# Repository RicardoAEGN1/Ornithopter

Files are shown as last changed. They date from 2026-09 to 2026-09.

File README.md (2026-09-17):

# 🚁 ORNITHOPTER

> Drone quadcóptero estilo **Dune** (thopter), controlado por **ESP32** com firmware open-source **ESP-Drone** (Espressif). Projeto escolar de eletrónica — construído componente a componente, sem kits.

**📖 Site do projeto (GitHub Pages):** https://ricardoaegn1.github.io/Ornithopter/ — apresentação, BOM interativo e todos os docs.

## Esquema de ligações (visão geral)

Esquema de ligações Ornithopter

*Raspberry Pi (estação de solo, sem soldas) → Wi-Fi → ESP32 no drone → 4 motores com MOSFETs + IMU. Ordem de soldadura e legenda no diagrama; detalhes em [`docs/wiring.md`](docs/wiring.md) e [`docs/ground-station.md`](docs/ground-station.md).*

## Números-chave

| Métrica | Valor |
|---|---|
| Peso total (AF) | ~78 g |
| Empuxo | ~150 g (razão 2,0×) |
| Autonomia | 6–11 min |
| Custo total | **44,30 €** (orçamento 70 €) |
| Loop de controlo | PID 500 Hz |
| Controlo | App iOS/Android via Wi-Fi 2,4 GHz |

## Estrutura

```
docs/               Viabilidade, BOM (CSV p/ Excel), pinout, plano de construção
cad/                Modelo paramétrico OpenSCAD (frame + carenagem estilo Dune)
presentation/       Apresentação HTML do projeto (abrir no browser)
ground-station/     Estação de solo em Raspberry Pi (visão + controlo autónomo)
assets/             Esquema à mão do criador + diagrama de ligações SVG
tools/              build_site.py — gera o site do GitHub Pages
site/               (gerado) site estático publicado no Pages
```

> O site (`site/`) é gerado automaticamente por `.github/workflows/pages.yml` a cada push para `main`.

## Arquitetura (v2 — autonomia)

```
Telemóvel/PC ──► Raspberry Pi (câmara + OpenCV) ──UDP/CRTP──► ESP32 ──► 4 motores
      painel         seguimento ArUco · altitude ·       PID interno · mixer
                     rotação · velocidades/direção       (firmware esp-drone)
```

O drone leva um marcador ArUco; a RPi calcula posição/altitude/rotação por visão e envia
setpoints — ver [`docs/ground-station.md`](docs/ground-station.md).

## Documentos

- [`docs/viability.md`](docs/viability.md) — estudo de viabilidade (arquitetura, empuxo/peso, potência, estabilidade)
- [`docs/bom.md`](docs/bom.md) — lista de materiais com fornecedores e custos
- [`docs/bom.csv`](docs/bom.csv) — mesma lista em CSV (abre no Excel com colunas certas)
- [`docs/ground-station.md`](docs/ground-station.md) — estação de solo RPi: visão, controlo, segurança
- [`docs/algorithms.md`](docs/algorithms.md) — sistemas e algoritmos: camadas de controlo, PID cascata, mixer, coordenação e multi-drone
- [`ground-station/main.py`](ground-station/main.py) — skeleton executável (FastAPI + OpenCV)
- [`docs/wiring.md`](docs/wiring.md) — pinout ESP32 e esquema de ligações
- [`docs/build-plan.md`](docs/build-plan.md) — plano de construção em blocos com critérios de passe
- [`cad/ornithopter.scad`](cad/ornithopter.scad) — CAD paramétrico (OpenSCAD → STL)
- [`presentation/ornithopter.html`](presentation/ornithopter.html) — apresentação do projeto

## Stack

| Camada | Tecnologia |
|---|---|
| Flight controller | ESP32-WROOM-32 (escola) |
| Firmware | [espressif/esp-drone](https://github.com/espressif/esp-drone) (ESP-IDF v5.0, GPL-3.0) |
| IMU | MPU-9250 (I2C) |
| Motores | 4× coreless 8520 + MOSFET AO3400A |
| Bateria | LiPo 1S 450 mAh 25C |
| App | [ESP-Drone-Android](https://github.com/EspressifApps/esp-drone-android) / iOS |
| Estação de solo | Raspberry Pi 4 + OpenCV (ArUco) · FastAPI |
| CAD | OpenSCAD |

*"The spice must flow."* 🕌

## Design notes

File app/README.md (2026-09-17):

# 📱 Ornithopter App (Expo)

App de controlo do drone Ornithopter em **Expo/React Native** — corre em Android/iOS via Expo Go, sem compilar nada.

## Arquitetura de comando

```
TELEMÓVEL (app Expo)      RASPBERRY PI (FastAPI)         ESP32 (esp-drone)
┌──────────────────┐     ┌──────────────────────┐      ┌───────────────┐
│ botões + telem.  │────►│ POST /takeoff /land  │────► │ mixer → 4     │
│ telemetria live  │◄────│ WS   /ws/telemetry   │◄──── │ motores + IMU │
└──────────────────┘HTTP └──────────────────────┘ UDP  └───────────────┘
```

- A app **nunca** fala com o drone diretamente — só com a estação de solo (RPi). É ela que aplica as regras de segurança (watchdog, geofence, bateria) a *qualquer* comando, venha ele da app, do painel web ou de um script.
- Telemetria em tempo real por WebSocket (`/ws/telemetry`): modo, posição x/y/z, atitude, bateria, estado do marcador.

## Ecrãs

1. **Ligação** — IP da estação de solo (rede da escola)
2. **Painel** — telemetria live + DECOLAR / ATERRAR
3. **EMERGENCY** — botão sempre visível, motores OFF imediato
4. *(próximo)* **Joystick virtual** — 2 pans → `/goto x,y`

## Correr

```bash
cd app
npm install
npx expo start        # abre no telemóvel com Expo Go (mesma rede Wi-Fi da RPi)
```

## Integração com a estação de solo

A app consome exatamente os endpoints já definidos em [`docs/ground-station.md`](../docs/ground-station.md):

| App | Endpoint RPi |
|---|---|
| LIGAR | `GET /` (painel) + `WS /ws/telemetry` |
| DECOLAR | `POST /takeoff` |
| ATERRAR | `POST /land` |
| Ir para (x,y) | `POST /goto?x=&y=` |
| EMERGENCY | `POST /emergency` |

## Estado

- [x] Esqueleto Expo (ligação, telemetria, comandos de voo)
- [ ] Joystick virtual (gestos → /goto)
- [ ] Modo FPV (stream MJPEG da câmara da RPi) — **extra**
- [ ] Config persistente do IP (AsyncStorage)

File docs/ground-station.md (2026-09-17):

# Estação de Solo — Raspberry Pi (backend de controlo)

> A Raspberry Pi da escola recebe comandos da **app Expo (telemóvel)** e do painel web, aplica as regras de segurança e envia setpoints ao ESP32. A **câmara** é um **extra opcional** de demonstração (seguimento autónomo por ArUco) — o drone voa e é comandável mesmo sem ela.

## 1. Modos de operação

| Modo | Câmara | Seguimento | Quem comanda |
|---|---|---|---|
| **A — Manual (base)** | ❌ | ❌ | App Expo / painel web → RPi → drone |
| **B — Autónomo (extra)** | ✔ | ✔ ArUco | Mission planner da RPi (demo de capacidade) |

No modo A, a altitude e a estabilização ficam a cargo do firmware (height-hold com barómetro BMP280 opcional) e dos comandos diretos da app. O modo B demonstra coordenação por visão — é o *show-off* científico, não o requisito.

## 2. Arquitetura

```
        ┌───────────────────────────── Wi-Fi 2,4 GHz ─────────────────────────────┐
        │                 UDP · protocolo CRTP (Crazyflie)                        │
        ▼                                                                         │
┌──────────────────┐        ┌──────────────────────────────────────────────────┐  │
│  ORNITHOPTER     │        │  RASPBERRY PI 4 (estação de solo)                │  │
│  ESP32 + MPU9250 │◄───────│  · câmara aponta para a zona de voo              │  │
│  firmware        │  setp. │  · OpenCV: deteta o marcador no drone            │  │
│  esp-drone       │        │  · calcula x, y, z (altitude), roll, pitch, yaw  │  │
└──────────────────┘        │  · PID externo → velocidades por motor           │  │
        ▲                   │  · FastAPI: painel de controlo no browser        │  │
        │                   └──────────────────────────────────────────────────┘  │
        └────────────────── telemetria (estado) ─────────────────────────────────┘
```

**Porquê esta divisão?**
- O ESP32 mantém o **PID interno** (estabilização a 500 Hz com o IMU) — exige timing rígido, não deve partilhar com visão.
- A RPi faz o **loop externo** (posição/altitude a ~30 Hz) — é o padrão Crazyflie: *position controller* no chão, *stabilizer* no drone.
- Protocolo: **CRTP over UDP**, o mesmo que o cfclient usa — não inventamos nada.

## 3. Como é que o drone é seguido (extra opcional)

O drone leva um **marcador ArUco impresso** (4×4 cm) na parte de baixo/inferior da carenagem:

1. A câmara da RPi captura a ~30–60 fps.
2. OpenCV (dicionário `aruco.DICT_4X4_50`) devolve os 4 cantos do marcador.
3. De cada frame extraímos:
   - **x, y** (posição no plano) → centróide dos cantos, convertido para cm com calibração da câmara.
   - **z (altitude)** → `solvePnP` com o tamanho real do marcador (4 cm conhecidos) — sem sensor extra!
   - **yaw (rotação)** → ângulo do vetor entre cantos do marcador.
   - **roll/pitch estimados** → mudança da forma aparente do quadrilátero (aproximação; o roll/pitch fino continua a vir da telemetria do IMU).
4. Um PID externo compara com o alvo (ex.: pairar a 50 cm sobre um ponto) e gera **setpoints de roll/pitch/thrust/yaw-rate**.
5. Os setpoints vão por UDP ao ESP32, que os mistura nos 4 motores.

**Alternativa ainda mais simples (Plano B):** 2 marcadores de cores (uma em cada braço frontal) → OpenCV `inRange` por cor → mais robusto a distância e luz, sem dependência do módulo `cv2.aruco`.

## 3. Controlo por app Expo (telemóvel)

O telemóvel fala **sempre com a RPi** (nunca com o drone):

```
app Expo ──HTTP POST /takeoff /land /goto /emergency──► RPi ──UDP──► ESP32
app Expo ◄──WebSocket /ws/telemetry (10 Hz)──────────── RPi ◄─────── ESP32
```

- **Porquê passar sempre pela RPi?** Ponto único de segurança: a RPi valida geofence, bateria e watchdog **antes** de retransmitir qualquer comando — venha ele da app, do painel web ou do planner autónomo.
- A app (pasta `app/`) tem: ecrã de ligação por IP, telemetria live, DECOLAR/ATERRAR e botão EMERGENCY sempre visível.
- *Extra:* stream MJPEG da câmara no ecrã da app (FPV pela RPi) — só útil no modo B.

## 4. Mapa das funções que propuseste → implementação

| Função (a tua ideia) | Onde corre | Como |
|---|---|---|
| **Calcular altitude** | RPi (visão) | `solvePnP` com marcador ArUco de 4 cm conhecidos |
| **Fazer o seguimento dos corpos em tempo real** | RPi (visão) | OpenCV ArUco / cores; IDs diferentes = "corpos" diferentes (multi-drone no futuro) |
| **Gerir o movimento do drone** | RPi (controle) | Máquina de estados: IDLE→TAKEOFF→HOVER→GOTO→LAND + PID externo |
| **Calcular a rotação atual do drone** | RPi (visão) + ESP32 (IMU) | Yaw do marcador por visão; roll/pitch finos por telemetria CRTP do IMU |
| **Calcular a velocidade a usar em cada motor e a direção** | ESP32 (mixer) | Setpoints → PID interno → mistura X: `M1=T−P−R+Y, M2=T+P−R−Y, M3=T+P+R+Y, M4=T−P+R−Y` |

## 6. Endpoints do painel e da app (FastAPI)

| Método | Rota | Ação |
|---|---|---|
| GET | `/` | Painel com vídeo + telemetria ao vivo |
| POST | `/takeoff` | Decolagem para altitude alvo (default 50 cm) |
| POST | `/land` | Aterrar |
| POST | `/goto {x,y,z}` | Ir para ponto |
| POST | `/emergency` | Motores OFF imediatamente |
| WS | `/ws/telemetry` | Telemetria em tempo real (x, y, z, r/p/y, bateria) |

## 7. Segurança

- Botão físico de **kill** na RPi (GPIO) e comando `/emergency` sempre ativo.
- **Watchdog:** se a RPi perder o marcador > 1 s → `LAND` automático.
- Geofence por software (zona de voo máx. 2×2 m, altura máx. 1,5 m).
- Bateria do drone < 3,4 V → aterragem automática.
- Sempre: voo amarrado nas primeiras sessões.

## 8. Requisitos (tudo grátis, tudo na escola)

```
Raspberry Pi 4 (escola) + câmara CSI/USB (escola)
Python 3.9+ · opencv-python · opencv-contrib-python (aruco) · fastapi · uvicorn · numpy
ESP32 já a correr esp-drone (modo CRTP over UDP já suportado)
```

---

*Referência: arquitetura cfclient/Crazyflie (position controller externo + stabilizer interno) e `espressif/esp-drone`.*

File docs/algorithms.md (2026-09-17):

# Sistemas e Algoritmos — Coordenação, Navegação e Controlo

> Documento teórico do Ornithopter: como as partes se coordenam (RPi ↔ ESP32 ↔ motores) e que algoritmos fazem o drone pairar, navegar e aterrar. Sem código — só conceitos, diagramas e matemática.

## 1. Visão global: três camadas de controlo

```
┌──────────────────────────────────────────────────────────────┐
│  CAMADA 3 — MISSION PLANNER (RPi, ~1 Hz)                     │
│  máquina de estados: IDLE → TAKEOFF → HOVER → GOTO → LAND    │
│  decide O QUÊ fazer (pontos de passagem, geofence, segurança)│
├──────────────────────────────────────────────────────────────┤
│  CAMADA 2 — POSITION CONTROLLER (RPi, ~30 Hz)                │
│  PID externo: posição (x,y,z) → setpoints de atitude         │
│  decide COMO se mover (roll/pitch/thrust desejados)          │
├──────────────────────────────────────────────────────────────┤
│  CAMADA 1 — STABILIZER (ESP32, 500 Hz)                       │
│  PID interno: atitude desejada → velocidades dos 4 motores   │
│  (mixer X) usando o giroscópio/accelerómetro do MPU-9250     │
└──────────────────────────────────────────────────────────────┘
```

Esta divisão é o padrão da indústria (Crazyflie, PX4, ArduPilot): **quanto mais rápido o loop, mais perto do hardware**. O ESP32 não sabe "para onde ir" — só sabe manter a atitude que lhe mandam; a RPi não toca nos motores — só manda intenções.

## 2. Estimador de atitude (ESP32): filtro complementar

O giroscópio é rápido mas deriva; o acelerómetro é estável mas ruidoso. O **filtro complementar** junta os dois:

```
ângulo = α · (ângulo + gyro · dt) + (1 − α) · atan2(acc_y, acc_z)

α ≈ 0,98  →  confia 98 % no gyro entre medições,
             corrige 2 % com o acelerómetro (que conhece "para baixo")
```

- Frequência de corte: `α = τ/(τ+dt)`, com τ ≈ 0,5 s.
- O yaw não pode ser corrigido pelo acelerómetro (a gravidade não gira no plano horizontal) → usa-se o **magnetómetro** do MPU-9250, ou aceita-se deriva lenta de yaw (ok para demo indoor).

## 3. PID em cascata (ESP32): o coração da estabilização

Dois PIDs encadeados por eixo (roll, pitch, yaw-rate):

```
setpoint atitude (graus)          ← vem da RPi
        │
        ▼
  ┌─────────┐  erro de ângulo   ┌─────────┐  velocidade
  │ PID     │ ────────────────►  │ PID     │ ───────────►  mistura
  │ ANGULAR │   (graus)          │ RATE    │               X (M1..M4)
  └─────────┘                    └─────────┘                    │
        ▲                             ▲                        ▼
   ângulo estimado               gyro (rad/s)          PWM 20 kHz nos MOSFETs
   (filtro compl.)               a 1 kHz
```

**Porquê cascata?** O loop interno (rate) é 10× mais rápido e amortece perturbações (rajadas, vibração) antes de chegarem ao ângulo — o mesmo princípio de um piloto automático real.

**Sintonia (Ziegler–Nichols na bancada):**
1. Ki = Kd = 0; subir Kp até oscilar → Kp_final = 0,6·Kp_osc
2. Kd ≈ 0,1·Kp (amortecer); Ki pequeno (corrigir deriva de hover)
3. Valores de partida típicos para mini-quads: rate Kp≈0,25 · angular Kp≈4,5

## 4. Mistura X (mixer): setpoints → 4 motores

```
M1 (CCW) = T − P − R + Y      M2 (CW)  = T + P − R − Y
M4 (CW)  = T − P + R − Y      M3 (CCW) = T + P + R + Y

T = thrust  P = pitch  R = roll  Y = yaw-rate
```

| Movimento | O que muda |
|---|---|
| Subir | T igual nos 4 |
| Pitch (frente/trás) | diferença frente ↔ trás |
| Roll (esq/dir) | diferença esquerda ↔ direita |
| Yaw (rodar) | pares CW vs CCW (torque reação) |

Cada Mi é normalizado a [0..1] antes do PWM. Se algum ultrapassa 1 (saturação), reduz-se T igualmente nos 4 — mantém a atitude em vez do empuxo (regra de segurança).

## 5. Algoritmos de coordenação RPi ↔ drone

### 5.1 Seguimento visual (ArUco)

1. Detetar cantos do marcador (dicionário 4×4) a 30 fps.
2. `solvePnP`: com 4 cantos + tamanho real (40 mm) → rotação e translação da câmara → **x, y, z do drone**.
3. Suavizar com **filtro de Kalman 1D** por eixo (prevê entre frames; rejeita outliers de deteção falhada).
4. Se perdido > 1 s → trigger de segurança (LAND).

### 5.2 Controlo de posição (PID externo na RPi)

```
erro_x = x_alvo − x_drone  →  pitch_cmd = Kp·erro_x + Ki·∫erro + Kd·(derivada)
erro_z = z_alvo − z_drone  →  thrust_cmd = hover_thrust + PID_z(erro_z)
```

- **Estratégia antiderivada (derivative kick):** derivar a medição, não o erro — evita saltos quando o alvo muda.
- **Integral limitado (anti-windup):** clampa ∫ para não acumular enquanto o drone arranca.

### 5.3 Máquina de estados (mission planner)

```
        takeoff()            z ≥ 95% alvo          goto(x,y)
IDLE ───────────► TAKEOFF ────────────────► HOVER ◄────► GOTO
  ▲                  │                        │             │
  │ land()/auto      │ perdeu marcador        │             │ chegou (<40mm)
  ▼                  ▼                        ▼             ▼
LAND ◄──────── bateria<3.4V ◄── watchdog ── (qualquer estado)
  │
  ▼ z≈0 → motores OFF → IDLE
```

Transições de emergência (watchdog, geofence, bateria) têm **prioridade absoluta** sobre comandos do utilizador.

### 5.4 Coordenação multi-"corpos" (extensão futura)

O dicionário ArUco 4×4 tem 50 IDs → cada drone pode ter um ID. A RPi faz **seguimento simultâneo** e um **alocador de alvos** evita colisões:
- **Caixas de exclusão:** cada drone tem um cilindro de 50 cm; o planner rejeita alvos dentro do cilindro de outro.
- **Prioridade fixa por ID** (determinístico, fácil de explicar na defesa).
- **Alternativa elegante:** algoritmo *repulsion* — cada drone recebe um empurrão virtual proporcional à proximidade do outro (campo potencial artificial).

## 6. Segurança por camadas (defesa em profundidade)

| Camada | Mecanismo | Atuação |
|---|---|---|
| 1 — Hardware | pull-down nos gates | motores OFF se ESP32 reinicia |
| 2 — Firmware | failsafe RC/Wi-Fi | perdeu ligação → motores OFF |
| 3 — Software RPi | watchdog do marcador | LAND automático |
| 4 — Mission | geofence + bateria | rejeita alvos fora; LAND < 3,4 V |
| 5 — Humano | botão EMERGENCY / kill | motores OFF imediato |

## 7. O que medir na bancada (para provar na defesa)

- Latência RPi→ESP32 (setpoint): alvo < 50 ms (Wi-Fi local)
- Latência de loop de visão: alvo < 33 ms/frame (30 fps)
- Erro estático de hover: alvo < ±10 cm (x,y) e < ±5 cm (z)
- Overshoot no degrau de setpoint: alvo < 20 % da altura degrau

---

*Referências: filtro complementar (Kalman/colibry), PID cascata do Crazyflie (`bitcraze/crazyflie-firmware`), ArUco (S. Garrido-Jurado, 2014), mistura X do esp-drone.*

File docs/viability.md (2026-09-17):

# Ornithopter — Estudo de Viabilidade

> Drone estilo **Dune** (thopter), controlado por **ESP32** com firmware open-source **ESP-Drone** (Espressif). Mini brushed, voo estabilizado por app de telemóvel via Wi-Fi. Orçamento máximo: **70 €**.

---

## 1. Decisão de arquitetura

**Porquê um quadcóptero com carenagem estilo Dune (e não um ornitóptero de asas batentes)?**

| Critério | Ornitóptero real (asas batem) | Quadcóptero "thopter" |
|---|---|---|
| Controlo de voo | Muito difícil (ninguém faz estabilização académica disto) | Maduro: firmware Crazyflie/ESP-Drone pronto |
| Risco de não voar | Alto | Baixo |
| Estética Dune | Exata | Adaptada (asas fixas escondem os 4 rotores) |
| Foco do trabalho | Mecânica (ruido, falha) | Eletrónica + software (o que a aula avalia) |

**Veredicto:** quadcóptero X-frame com uma carenagem superior em forma de "thopter" e 4 anéis de proteção estilo motor-gondola de Dune. Voa de verdade e tem a estética.

## 2. Configuração de voo

- **Frame:** X quadrado, 65–80 mm (motor-to-motor), chassi em PLA/PETG impresso 3D ou contraplacado 2 mm.
- **Motores:** 4 × **8520 coreless brushed** (8,5 mm × 20 mm), 3,7 V, ~55 000 rpm, ~15–20 g de empuxo cada a 3,7 V.
- **Hélices:** 65 mm (2 pares CW + CCW), tipo *Gemfan 65mm* — o par CW/CCW é o que permite ao firmware contrariar o *torque* (yaw).
- **Bateria:** **1S LiPo 300–450 mAh** (3,7 V nominal, 4,2 V carregada), com conector JST-PH 2.0.
- **Controlador:** **ESP32-WROOM-32** (fornecido pela escola) — faz de *flight controller* + *radio link* Wi-Fi (2,4 GHz), sem rádio extra.
- **IMU:** **MPU-9250** (giroscópio + acelerómetro + magnetómetro, I2C/SPI) — recomendado pelo schematic do ESP-Drone; alternativas: MPU-6050 (só giro+acc) ou ICM-42688.
- **Driver dos motores:** 4 × MOSFET N-channel em SOT-23 (ex.: **AO3400A**) com resistor de gate 100 Ω e flyback diode, um por motor — é a arquitetura do schematic oficial do ESP-Drone.

## 3. Contas de voo (a parte que interessa provar)

**Peso estimado (AF — all-up weight):**

| Componente | Peso |
|---|---|
| 4 × motor 8520 | ~4 × 5,0 g = 20 g |
| 4 × hélice 65 mm | ~4 × 0,5 g = 2 g |
| Bateria 1S 450 mAh | ~13 g |
| ESP32-WROOM-32 (devkit) | ~10 g |
| MPU-9250 breakout | ~2 g |
| Chassi + carenagem PLA | ~20–25 g |
| Cablagem, MOSFETs, parafusos, LEDs | ~8 g |
| **Total** | **~75–80 g** |

**Empuxo:** 4 motores × ~17 g = **~68 g** a 3,7 V... insuficiente para um AF de 80 g.
- A 4,0–4,2 V (bateria cheia) o empuxo sobe para ~22 g/motor → **~88 g**.
- **Regra de ouro:** empuxo ≥ 2× peso. Para AF = 80 g queremos **~160 g de empuxo**.
- **Solução:** usar a variante **820 coreless (55 000 rpm, ~25 g empuxo)** ou motores 8520 "high thrust" (~24 g), ou reduzir o AF para <45 g com chassi minimalista (estilo Crazyflie: ~27 g).

**Alvo final:** AF ≈ 70 g, empuxo ≈ 140–160 g → razão empuxo/peso **2,0–2,3** ✔ (hover a ~45–50 % de throttle, sobra para manobrar).

**Corrente:** 4 motores × ~0,6 A em hover ≈ **2,4 A**; pico ~5 A. Uma 1S 450 mAh a 25C entrega 11 A — folga ✔.
**Autonomia:** 450 mAh / 2,4 A ≈ **11 min em hover** (realista: 6–8 min com manobras).
**Potência:** 3,7 V × 2,4 A ≈ **9 W em hover**, ~18 W pico.

## 4. Estabilidade (o que o firmware faz)

- **Loop de controlo a 500 Hz:** PID em cascata (rate → attitude), igual ao Crazyflie. O MPU-9250 mede rotações a 1 kHz.
- **Modos:** *Stabilize* (ângulos limitados, sempre estável), *Height-hold* (com barómetro BMP280 opcional, +2 €) e *Position-hold* (com fluxo ótico PMW3901, +12 € — opcional, fica fora do orçamento base).
- **Mistura X:** firmware mistura throttle + roll + pitch + yaw nos 4 motores (M1..M4), CW/CCW alternados.

## 5. Ligações (esquema elétrico resumido)

```
Bateria 1S ──┬── VCC 3,7V ──┬─────────────┬──────────────┐
             │              │             │              │
           (SW)          MOSFET M1..M4 (AO3400A)    VIN ESP32
             │              │             │              │
             └── GND ───────┴── GND ──────┴──────────────┘
                            ▲
              Gate de cada MOSFET ◄── GPIO 4/12/13/14 (ESP32) via 100Ω
              MPU-9250: SDA→GPIO21, SCL→GPIO22 (I2C, 3V3 + GND)
```

- Motores: + do motor ao + da bateria; − do motor ao **drain** do MOSFET; **source** ao GND.
- ESP32 alimenta-se pela bateria via pino **VIN/5V** (regulador onboard aguenta 4,2 V — confirmar devkit).
- LEDs indicadores em GPIO 2 (e ring WS2812 opcional para efeito "spice" laranja de Dune).

## 6. Software (o que já existe, não inventamos)

- **Firmware:** `espressif/esp-drone` (GitHub) — GPL3.0, portado do Crazyflie. Suporta ESP32/ESP32-S2/S3, IDF v5.0.
- **App:** `ESP-Drone-iOS` / `ESP-Drone-Android` (open-source) — liga por Wi-Fi ao drone e controla.
- **O que fazemos:** configurar GPIOs no `menuconfig` para os nossos pinos, calibrar IMU, ajustar PID.

## 7. Riscos e mitigação

| Risco | Mitigação |
|---|---|
| Empuxo insuficiente | Motores "high thrust" ou chassi < 50 g; testar empuxo antes de montar |
| Peso da carenagem | Carenagem em PLA fino (0,8 mm) ou cartão plástico; ≤ 25 g |
| IMU barata descalibrada | Calibração do firmware + montagem firme com espuma dupla-face |
| Interferência Wi-Fi no IMU | Afastar MPU-9250 do ESP32 ≥ 2 cm; fios torcidos |
| Soldadura de MOSFET SOT-23 | Usar adaptador SOT-23→DIP ou MOSFET TO-92 (mais fácil de soldar) |

---

*Fonte: repositório `espressif/esp-drone` (GitHub), especificações típicas de motores coreless 8520/820 de fabricantes (estimativas), cálculos próprios.*

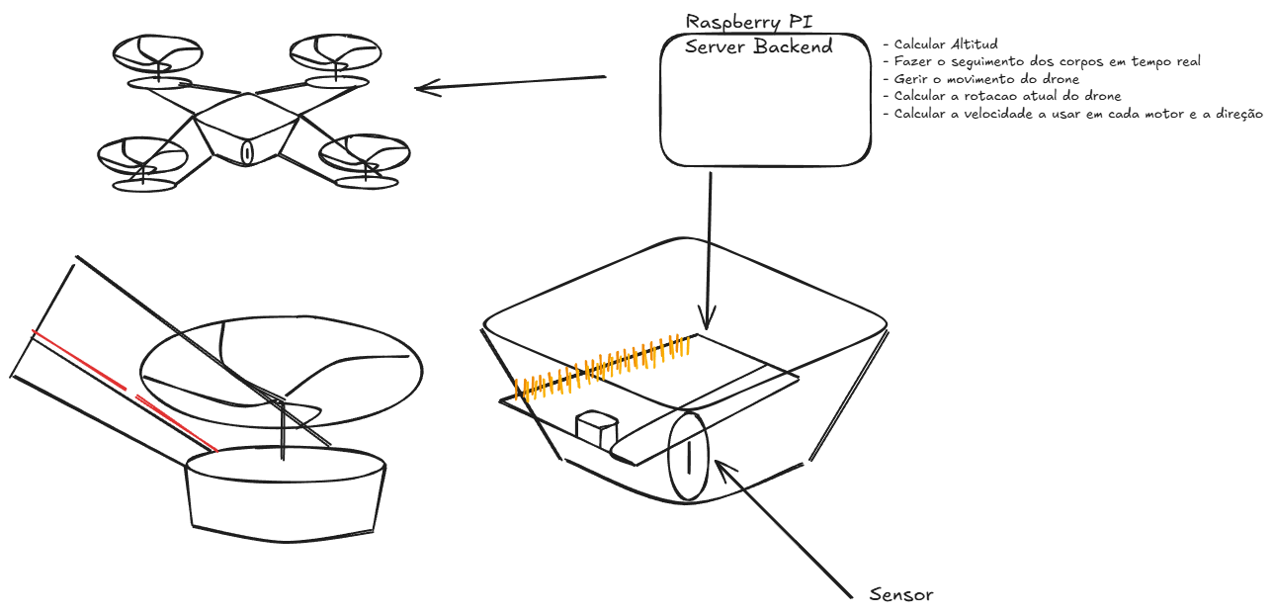
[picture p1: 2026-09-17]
assets/schema-raspberry-v1.png

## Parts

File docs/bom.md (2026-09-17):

# Ornithopter — Lista de Materiais (BOM)

> Orçamento máximo: **70 €**. A escola fornece: **ESP32 devkit, ferro de soldar + estanho, cabos, multímetro** (valor evitado: ~15 €).

## 1. Componentes comprados

| # | Componente | Especificação | Fornecedor | Qtd | Preço un. | Subtotal |
|---|---|---|---|---|---|---|
| 1 | Motores coreless 8520 "high thrust" | 8,5×20 mm, 3,7 V, ~24 g empuxo (2× CW + 2× CCW) | AliExpress / Amazon.es | 4 | 2,50 € | **10,00 €** |
| 2 | Hélices 65 mm (2 CW + 2 CCW) | Gemfan 65 mm ou equivalentes | AliExpress / Amazon.es | 4 (+4 reserva) | 0,40 € | **3,20 €** |
| 3 | Bateria LiPo 1S 450 mAh 25C | Com JST-PH 2.0 e protetor | AliExpress / loja RC local | 1 | 7,50 € | **7,50 €** |
| 4 | Carregador 1S USB (micro/USB-C) | Balanceador simples 1S | AliExpress / loja RC local | 1 | 6,00 € | **6,00 €** |
| 5 | IMU MPU-9250 (GY-9250 breakout) | Giro + acel + mag, I2C/SPI | AliExpress / Amazon.es | 1 | 4,50 € | **4,50 €** |
| 6 | MOSFET AO3400A (ou TO-92 equivalente) | N-channel, gate 2,5–4 V | AliExpress (lote 50 pcs) | 4 | 0,10 € | **0,40 €** |
| 7 | Resistores (100 Ω gate, 10 kΩ pull-down) | Kit básico 1/4 W | Escola ou AliExpress | 8 | 0,05 € | **0,40 €** |
| 8 | Flyback diodes 1N4148 | Proteção dos MOSFETs | Escola / AliExpress | 4 | 0,05 € | **0,20 €** |
| 9 | Conector JST-PH 2.0 (par) | Fio para bateria→placa | AliExpress | 1 | 1,00 € | **1,00 €** |
| 10 | Fio silicone 22 AWG (verm/preto) | 1 m de cada | Escola / AliExpress | 1 | 2,00 € | **2,00 €** |
| 11 | Proto-board perfurada ou placa DIY | Base para montar os MOSFETs | Loja eletrónica local | 1 | 3,00 € | **3,00 €** |
| 12 | Filamento PLA (chassi + carenagem) | ~40 g; impressão na escola ou 3DHub | Escola (grátis) ou serviço | 1 | 4,00 € | **4,00 €** |
| 13 | LEDs + resistores (indicador laranja "spice") | 5 mm + 220 Ω | Escola / AliExpress | 2 | 0,10 € | **0,20 €** |
| 14 | Velcro dupla-face + abraçadeiras | Fixação bateria e IMU | Loja local | 1 | 1,50 € | **1,50 €** |
| 15 | Parafusos M2 + porcas | Montagem motores | Loja local / escola | 8 | 0,05 € | **0,40 €** |

**Total comprado: ≈ 44,30 €** ✔ dentro dos 70 € (folga de ~25 € para portes, reservas e imprevistos).

## 2. Componentes fornecidos pela escola (custo 0 €)

| Componente | Valor evitado |
|---|---|
| ESP32 devkit (WROOM-32) | ~8,00 € |
| Ferro de soldar + estanho + fluxo | ~20,00 € |
| Cabos jumpers / fio | ~2,00 € |
| Multímetro (testes) | ~10,00 € |
| **Total evitado** | **~40,00 €** |

## 3. Opcionais (se sobrar orçamento)

| Componente | Preço | Efeito |
|---|---|---|
| Barómetro BMP280 | ~2 € | Modo *height-hold* do firmware |
| Fluxo ótico PMW3901 | ~12 € | Modo *position-hold* (hover sem deriva) |
| Anel LED WS2812 | ~2 € | Efeito visual "spice" laranja |

## 4. Notas de compra

- **AliExpress:** mais barato mas 2–4 semanas de espera → encomendar **já**.
- **Amazon.es:** entrega 24–72 h, ~30 % mais caro — usar para bateria e carregador (críticos).
- **Lojas PT:** Robotshop.pt, Bricogeek (ES), lojas RC locais para bateria/hélices de reserva.
- Comprar **2 baterias** se possível: uma voa, outra carrega (a aula de demonstração fica garantida).

---

*Preços: estimativas realistas de loja (AliExpress/Amazon.es), set. 2026. Confirmar no checkout.*

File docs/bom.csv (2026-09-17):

# COMPONENTE | ESPECIFICACAO | FORNECEDOR | QTD | PRECO UNITARIO (EUR) | SUBTOTAL (EUR) | LINK
Motor coreless 8520 high thrust | 8,5x20 mm 3,7V ~24g empuxo (2x CW + 2x CCW) | AliExpress / Amazon.es | 4 | 2,50 | 10,00 | https://pt.aliexpress.com/w/wholesale-8520-coreless-motor.html
Helices 65 mm CW/CCW | Gemfan 65mm ou equivalente (+4 reserva) | AliExpress / Amazon.es | 8 | 0,40 | 3,20 | https://pt.aliexpress.com/w/wholesale-65mm-propeller.html
Bateria LiPo 1S 450 mAh 25C | Com JST-PH 2.0 e protecao | Amazon.es / Loja RC local | 1 | 7,50 | 7,50 | https://www.amazon.es/s?k=lipo+1s+450mah+jst
Carregador LiPo 1S USB | Balanceador simples 1S | Amazon.es / Loja RC local | 1 | 6,00 | 6,00 | https://www.amazon.es/s?k=1s+lipo+charger+usb
IMU MPU-9250 | Breakout GY-9250 giro+acel+mag I2C | AliExpress / Amazon.es | 1 | 4,50 | 4,50 | https://pt.aliexpress.com/w/wholesale-gy-9250.html
MOSFET AO3400A | N-channel SOT-23 (lote) | AliExpress | 4 | 0,10 | 0,40 | https://pt.aliexpress.com/w/wholesale-ao3400a.html
Resistores 100R / 10k | Kit basico 1/4W | Escola / AliExpress | 8 | 0,05 | 0,40 | https://pt.aliexpress.com/w/wholesale-resistor-kit.html
Diodo flyback 1N4148 | Protecao MOSFET | Escola / AliExpress | 4 | 0,05 | 0,20 | https://pt.aliexpress.com/w/wholesale-1n4148-diode.html
Conector JST-PH 2.0 | Par femea/macho com fio | AliExpress | 1 | 1,00 | 1,00 | https://pt.aliexpress.com/w/wholesale-jst-ph-2.0.html
Fio silicone 22 AWG | 1m vermelho + 1m preto | Escola / AliExpress | 1 | 2,00 | 2,00 | https://pt.aliexpress.com/w/wholesale-22awg-silicone-wire.html
Proto-board perfurada | Base MOSFETs | Loja eletronica local / Amazon.es | 1 | 3,00 | 3,00 | https://www.amazon.es/s?k=placa+perfurada+proto
Filamento PLA | Frame + carenagem (~40g) | Escola (impressora 3D) | 1 | 4,00 | 4,00 | -
LED 5mm laranja + resistor 220R | Indicador spice | Escola / AliExpress | 2 | 0,10 | 0,20 | https://pt.aliexpress.com/w/wholesale-led-5mm.html
Velcro dupla-face + abracadeiras | Fixacao bateria e IMU | Loja local | 1 | 1,50 | 1,50 | -
Parafusos M2 + porcas | Montagem motores | Loja local / AliExpress | 8 | 0,05 | 0,40 | https://pt.aliexpress.com/w/wholesale-m2-screw-kit.html
Fornecido pela escola (0 EUR) | ESP32 devkit WROOM-32 | Escola | 1 | 0,00 | 0,00 | -
Fornecido pela escola (0 EUR) | Ferro de soldar + estanho | Escola | 1 | 0,00 | 0,00 | -
Fornecido pela escola (0 EUR) | Cabos jumpers | Escola | 1 | 0,00 | 0,00 | -
Fornecido pela escola (0 EUR) | Multimetro | Escola | 1 | 0,00 | 0,00 | -
Fornecido pela escola (0 EUR) | Raspberry Pi + camara (estacao de solo) | Escola | 1 | 0,00 | 0,00 | -
TOTAL COMPRADO |  |  |  |  | 44,30
ORCAMENTO MAXIMO |  |  |  |  | 70,00
FOLGA |  |  |  |  | 25,70

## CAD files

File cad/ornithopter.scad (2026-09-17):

// ============================================================
//  ORNITHOPTER — Drone estilo Dune (thopter)
//  Modelo CAD paramétrico (OpenSCAD) — chassi + carenagem
//  Abre em OpenSCAD (gratuito) e exporta STL para impressão 3D
// ============================================================

/* [Dimensões principais — mm] */
motor_spacing = 78;      // distância motor-a-motor (diagonal X)
arm_width     = 8;       // largura do braço
plate_t       = 2.0;     // espessura das placas (PLA)
motor_d       = 8.5;     // diâmetro do motor 8520
motor_h       = 20;      // altura do motor 8520
prop_d        = 65;      // hélice 65 mm
ring_w        = 3.2;     // espessura do anel de proteção (gondola)
canopy_h      = 14;      // altura da carenagem estilo thopter
hole_m2       = 2.2;     // furo M2 para motores

$fn = 64;

// ---------- Módulos ----------

// Braço do frame X (entre dois motores opostos)
module arm(len) {
    rotate([0,0,45])
        cube([len, arm_width, plate_t], center=true);
}

// Suporte do motor: anel + furos M2
module motor_mount() {
    difference() {
        cylinder(d = motor_d + 5, h = plate_t, center = true);
        cylinder(d = motor_d - 1.2, h = plate_t + 1, center = true); // cavity motor
        for (a = [0, 90, 180, 270])
            rotate([0, 0, a + 45])
                translate([(motor_d + 3) / 2, 0, 0])
                    cylinder(d = hole_m2, h = plate_t + 2, center = true);
    }
}

// Anel de proteção da hélice (gondola estilo Dune)
module prop_ring() {
    rotate_extrude()
        translate([prop_d/2 + 4, 0, 0])
            circle(d = ring_w);
}

// Corpo central: duas placas + espaçadores
module body() {
    half = motor_spacing / 2;
    // braços em X
    arm(motor_spacing * 1.45);
    mirror([0,1,0]) arm(motor_spacing * 1.45);
    // placa inferior
    translate([0, 0, -plate_t/2 - 6])
        cube([34, 34, plate_t], center = true);
    // placa superior
    translate([0, 0, plate_t/2 + 6])
        cube([34, 34, plate_t], center = true);
}

// Carenagem estilo "thopter": casco alongado com quilha
module canopy() {
    hull() {
        translate([0, 0, 8]) scale([1.6, 1, 0.55]) sphere(d = 22);
        translate([-26, 0, 4]) scale([1.2, 0.8, 0.4]) sphere(d = 16); // nariz
        translate([20, 0, 4]) scale([1.3, 0.85, 0.45]) sphere(d = 18); // cauda
    }
    // quilha ventral (estabilidade visual e antitombo)
    translate([0, 0, -1]) rotate([90, 0, 0])
        linear_extrude(height = 2, center = true)
            polygon([[-24,0],[24,0],[10,-9],[-14,-9]]);
}

// ---------- Montagem ----------

half = motor_spacing / 2;

module ornithopter() {
    body();
    // motores + anéis nos 4 cantos
    for (sx = [-1, 1], sy = [-1, 1])
        translate([sx * half, sy * half, 0]) {
            prop_ring();
            translate([0, 0, motor_h/2 + plate_t/2])
                %cylinder(d = motor_d, h = motor_h, center = true); // motor (fantasma)
        }
    canopy();
}

// Plana: Vista de topo da placa única do frame (para imprimir)
module frame_flat() {
    difference() {
        union() {
            arm(motor_spacing * 1.45);
            mirror([0,1,0]) arm(motor_spacing * 1.45);
            cube([34, 34, plate_t], center = true);
        }
        // alívio de peso central
        translate([0, 0, 0]) cube([22, 14, plate_t + 2], center = true);
        // furos dos motores
        for (sx = [-1, 1], sy = [-1, 1])
            translate([sx * half, sy * half, 0])
                for (a = [0, 90, 180, 270])
                    rotate([0, 0, a + 45])
                        translate([(motor_d + 3) / 2, 0, 0])
                            cylinder(d = hole_m2, h = plate_t + 2, center = true);
    }
}

// Escolher o que mostrar:
// ornithopter();   // vista completa com carenagem e anéis
frame_flat();       // vista da placa plana pronta a imprimir

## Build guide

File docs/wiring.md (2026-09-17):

# Ornithopter — Ligações ESP32 (pinout e esquema)

> Firmware: `espressif/esp-drone` (ESP-IDF v5.0). Pinos configuráveis no `menuconfig`.

Diagrama de ligações completo

## 1. Tabela de ligações

| Sinal | Pino ESP32 | Destino | Notas |
|---|---|---|---|
| Motor M1 (frente-direita, CCW) | GPIO 4 | Gate MOSFET 1 via 100 Ω | LEDC ch0 |
| Motor M2 (trás-direita, CW) | GPIO 12 | Gate MOSFET 2 via 100 Ω | LEDC ch1 |
| Motor M3 (trás-esquerda, CCW) | GPIO 13 | Gate MOSFET 3 via 100 Ω | LEDC ch2 |
| Motor M4 (frente-esquerda, CW) | GPIO 14 | Gate MOSFET 4 via 100 Ω | LEDC ch3 |
| IMU SDA | GPIO 21 | MPU-9250 SDA (I2C) | pull-up 4,7 kΩ a 3V3 |
| IMU SCL | GPIO 22 | MPU-9250 SCL (I2C) | pull-up 4,7 kΩ a 3V3 |
| IMU IRQ | GPIO 36 (input) | MPU-9250 INT | leitura síncrona |
| LED status | GPIO 2 | LED + 220 Ω → GND | onboard do devkit |
| VIN | 5V/VIN | + da bateria (via JST) | regulador onboard |
| GND | GND | − da bateria, sources MOSFETs | comum |

## 2. Cada motor (×4)

```
Bateria (+) ──────────────► fio vermelho do motor
GPIO ──[100 Ω]── Gate AO3400A
                 Drain ◄──── fio azul/branco do motor
                 Source ───► GND
                 (1N4148 entre Drain e +Bateria, catodo ao +)
10 kΩ entre Gate e GND (mantém motor parado se o ESP32 arranca a meio)
```

## 3. MPU-9250

```
ESP32 3V3 ──► VCC  |  GPIO21 ──► SDA  |  GPIO22 ──► SCL  |  GND ──► GND
Montar a ≥ 2 cm do ESP32, com fita dupla-face (isola vibrações)
```

## 4. Checklist de segurança antes de ligar

- [ ] Continuidade GND comum (multímetro)
- [ ] Sem curto +/− da bateria (medição com multímetro, antes do JST)
- [ ] MOSFET no sentido certo (Source ao GND!)
- [ ] Motores giram na direção certa (testar com app, hélices FORA)
- [ ] Primeiro voo amarrado com fio de pesca ao teto/mastro

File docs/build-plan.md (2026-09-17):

# Ornithopter — Plano de Construção (componente a componente)

> Filosofia da aula: **nada de kits perfeitos** — cada bloco é construído, testado e compreendido individualmente antes do seguinte.

## Bloco 0 — Antes de comprar (1 aula)

1. Imprimir `cad/ornithopter.scad` → exportar `frame_flat()` em STL → confirmar com o professor a impressão 3D.
2. Encomendar BOM (`docs/bom.md`) — AliExpress demora 2–4 semanas.
3. Instalar ESP-IDF v5.0 e clonar `espressif/esp-drone` (teste de compilação com placa vazia).

## Bloco 1 — Bancada de motores (sem voar)

1. Soldar 1 motor a 1 MOSFET numa protoboard com resistor de gate.
2. Acionar com um GPIO do ESP32 (sinal PWM 500 Hz do LEDC).
3. Medir corrente e empuxo numa balança de cozinha (motores apontando para baixo).
4. **Critério de passe:** ~20 g de empuxo por motor a 3,7 V.

## Bloco 2 — IMU e estimativa de atitude

1. Ligar MPU-9250 por I2C e ler registos brutos com exemplo do ESP-IDF.
2. Verificar que roll/pitch respondem corretamente ao inclinar a placa à mão.
3. Calibrar gyro (comando do firmware) com a placa imóvel.
4. **Critério de passe:** leitura estável ±2° com a placa parada.

## Bloco 3 — Firmware de voo

1. Configurar `menuconfig`: pinos dos motores, I2C, IMU.
2. Flash e ligar pela app ESP-Drone (Wi-Fi "ESPDRONE-xxxx").
3. Teste no chão: arm/disarm, resposta dos 4 motores aos comandos.
4. **Critério de passe:** os 4 motores respondem ao joystick, sem vibrar.

## Bloco 4 — Montagem completa

1. Montar motores no frame, cablar, fixar bateria com velcro.
2. Centro de gravidade no centro do frame X (deslizar a bateria até equilibrar).
3. Teste de voo amarrado (fio de pesca num mastro) — ajustar PIDs.
4. **Critério de passe:** hover estável > 10 s amarrado.

## Bloco 5 — Carenagem estilo Dune (só depois de voar!)

1. Imprimir/levar a carenagem leve (≤ 25 g).
2. Re-testar voo amarrado com carenagem.
3. Demonstração final: decolagem, hover, aterragem controlada.

## Checklist de segurança

- [ ] Hélices FORA em todos os testes elétricos
- [ ] Óculos de proteção ao testar hélices postas
- [ ] Bateria LiPo guardada em saco à prova de fogo, nunca abaixo de 3,3 V
- [ ] Nunca arm/disarm com hélices à frente de pessoas
- [ ] Carregar LiPo sempre supervisionado

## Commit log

2026-09-17 Initial commit: project documentation, CAD and presentation
    Feasibility study, BOM (44.30 EUR / 70 EUR budget), ESP32 wiring
    pinout, block-by-block build plan, parametric OpenSCAD model and
    HTML presentation for the Dune-style quadcopter drone.
    [ornithopter.scad]
2026-09-17 Add ground station (RPi vision+control) and BOM spreadsheet
    Raspberry Pi 4 ground station: ArUco marker tracking with OpenCV,
    external PID, state machine (takeoff/hover/goto/land/emergency) and
    UDP setpoints to the ESP32. BOM also exported as Excel-ready CSV.
    [bom.csv]
2026-09-17 Restyle presentation as hand-drawn document and add creator sketch
    New Excalidraw-style HTML presentation (grid paper, handwritten
    fonts, few colors) crediting the creator, embedding the hand-drawn
    RPi ground-station sketch in assets/ and links to the BOM.
2026-09-17 Add supplier search links column to BOM spreadsheet
    [bom.csv]
2026-09-17 Add wiring diagram, GitHub Pages workflow and site generator
    Hand-drawn style SVG wiring diagram (RPi, ESP32, IMU, motors,
    MOSFETs, soldering order) embedded in the README. GitHub Actions
    workflow builds site/ from the presentation, rendered docs and an
    interactive BOM table, and deploys it to GitHub Pages on push.
2026-09-17 Add systems & algorithms doc and embed wiring diagram in docs
    Theory-only deep dive: control layers, complementary filter,
    cascaded PID tuning, X mixer with saturation rule, RPi-drone
    coordination, state machine, multi-body expansion and layered
    safety. Wiring diagram now embedded in wiring.md; site nav and
    presentation updated with the algorithms section.
2026-09-17 Add Expo control app skeleton and make camera an optional extra
    Control chain is now phone (Expo) -> Raspberry Pi -> ESP32, with the
    RPi as the single safety point for any command source. Ground station
    doc gains operation modes: A manual (no camera, base) and B autonomous
    ArUco tracking (extra capability demo). Site nav links the app page.
